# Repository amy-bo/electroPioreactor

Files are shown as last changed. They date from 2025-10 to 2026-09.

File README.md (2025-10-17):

# electroPioreactor

The electroPioreactor is a [Pioreactor](https://pioreactor.com) adapted to incorporate electrolysis and CO2 sparging.  The main motivation is to facilitate affordable, safe, local production of Hydrogen Oxidising Bacteria (HOB) as a sustainable alternative protein.

Our parametric [Vial Cap](Components/Vial%20Cap/) design and bill of materials are detailed in [Components](Components).

This repo also contains summary outputs of past research projects including [Harvey Mudd](Past%20research/HMC%20Final%20Outputs)'s anode and valve optimisation work and Brown's [CO2 sparger backflow solution](Past%20research/1.%20CO2%20backflow%20diagnosis%20-%20Eli%20Silver.md).



## Aseptic electroPioreactor

A current focus is development and testing of an Aseptic electroPioreactor to facilitate research on monocultures. [Imperial College](https://profiles.imperial.ac.uk/s.billerbeck/grants) and [Edinburgh University](https://biology.ed.ac.uk/chris-french-laboratory) are leading this work under [CARMA Hub Pump Priming](https://carmahub.co.uk/about-us/pump-priming-projects/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) funding.

## GitHub & Radicle

This repo is synchronised both [via GitHub](https://github.com/amy-bo/electroPioreactor/tree/main) and [via Radicle](https://app.radicle.xyz/nodes/iris.radicle.xyz/rad%3AzY4GuyErQo91xGYdLi4r2bea9QDJ) we would encourage you to try [Radicle.xyz](https://radicle.xyz/).

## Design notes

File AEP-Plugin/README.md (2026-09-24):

# electroPioreactor-plugin

A [Pioreactor](https://pioreactor.com) community plugin for the **[electroPioreactor](https://electroPioreactor.org)** – any Pioreactor fitted with an electrode pair driven by LED D and a CO₂ solenoid driven by PWM channel 4.

Provides a single background job, **electroPioreactor**, that:

- Drives electrolysis (via LED channel D) at a user-defined power level (0–10 %, clamped at runtime to protect the electrodes).
- Sparges CO₂ by periodically opening a CO₂ solenoid (PWM channel 4 relay) for a user-defined duration, at a user-defined interval in minutes.
- Automatically pauses electrolysis (LED D → 0 %) for the duration of each sparge and resumes it immediately after.
- Pauses the `od_reading` job for the duration of the sparge plus a user-defined settle window, so OD samples aren't contaminated by bubbles.

All four user-defined parameters are editable live from the Pioreactor web interface.

### OD pausing

`od_pause_after_sparge_seconds` (default `5.0`) is the number of seconds **after the CO₂ solenoid closes** before OD reading resumes – the bubble-clearance window. The total OD pause window is `sparge_duration_seconds + od_pause_after_sparge_seconds`, measured from sparge start.

- **Positive** → pause OD for the full sparge plus N seconds of settle time. Typical.
- **Zero** → resume OD the instant the solenoid closes.
- **Negative** → resume OD part-way through the sparge (OD continues through the tail end of sparging).
- **≤ −`sparge_duration_seconds`** → total pause ≤ 0; OD is not paused at all. Use a large negative (e.g. `-99999`) to disable the feature entirely.

Pause/resume is done by publishing `JobState.SLEEPING`/`READY` to `od_reading`'s `$state/set` topic. If `od_reading` isn't running, the publish is a no-op.

## Hardware requirements

- Pioreactor with an electrode pair wired to **LED channel D**.
- CO₂ solenoid valve wired to **PWM channel 4**.
- CO₂ supply (e.g. SodaStream) ideally with a needle valve for flow control.

## Installation

### From the card

Needs a Pioreactor OS release with boot-partition plugin support (proposed at https://github.com/amy-bo/CustoPiZer/tree/bootfs-plugins and accepted by Pioreactor; until it ships, use the SSH route below).

1. Two changes to make while following Pioreactor's software set-up guide, which comes next:
   - At its step 3, in **App Options**, switch off **Eject media when finished** (1) before you set the **Content Repository** (2), so the card stays mounted after the write.

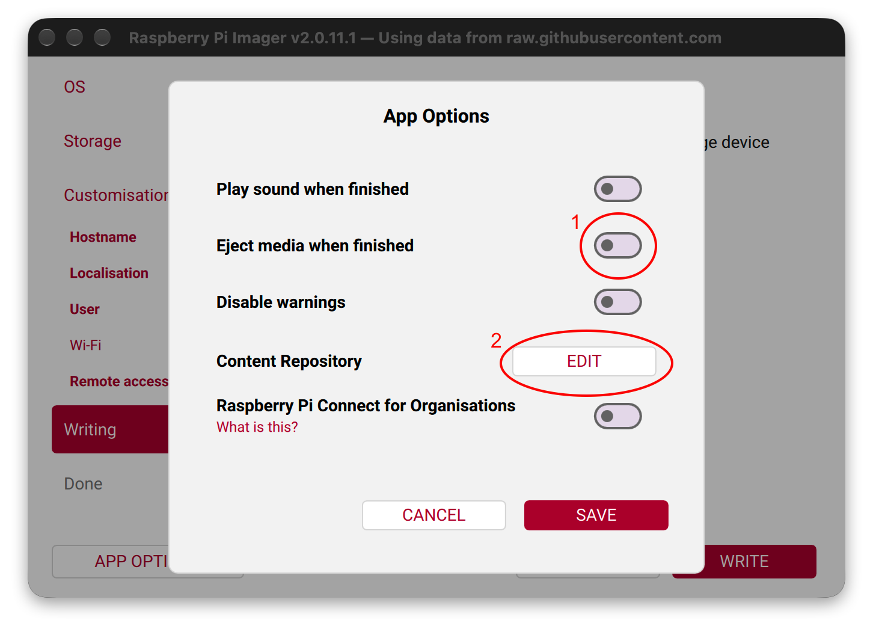
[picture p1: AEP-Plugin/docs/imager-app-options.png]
Imager's App Options: 1 Eject media when finished switched off, 2 Content Repository Edit
     

   - At its step 15, for your leader, leave the Wi-Fi page blank if you can't add devices to your lab's Wi-Fi then reach them through it (typical at universities); the leader Pioreactor then makes its own network.
   - Worker-only units: follow the same steps with a **Worker** image. Flash each worker with the step 15 Wi-Fi page set to network `pioreactor`, password `raspberry`, and at step 3 below do not drag the `local_access_point` file across. The plugin installs when you add the unit from the leader's **Inventory** page. Hotspot cluster: boot the leader first.

   With those in mind, follow [Pioreactor's software set-up guide](https://docs.pioreactor.com/user-guide/software-set-up) up to **Write**, and come back here while the card writes.
2. Download and unzip the [AEP card bundle](https://github.com/amy-bo/electroPioreactor/releases/latest/download/electroPioreactor-AEP-card-bundle.zip).
3. When the write finishes, drag the `pioreactor` folder from the bundle onto the `bootfs` drive. If you left the Wi-Fi page blank (for the leader Pioreactor to make its own network), also drag across the `local_access_point` file, after changing `GB` in it to your country code\*. DO NOT drag it across for workers, or if you set your Pioreactors up to join a Wi-Fi network. If the card was ejected anyway, remove and reinsert it.
4. Eject the card. One change to the rest of Pioreactor's guide: for a unit that makes its own Wi-Fi, join the network `pioreactor` (password `raspberry`) and open `http://pioreactor.local`. Then continue the guide from its step 18; the model dialog at its step 21 does not appear, because the bundle has set the model. **electroPioreactor** is under **Activities** on the unit's *Manage* page, and the precision temperature plugin is installed.

   \* If your country code is not GB, open `local_access_point` in TextEdit/Notepad and replace `GB` with the ISO two-letter code (CA, IE, DE, AU, NZ, GL, US, etc.; see https://en.wikipedia.org/wiki/ISO_3166-1_alpha-2) and save; the file should contain just those two letters. Do nothing if you live in the United Kingdom of Great Britain and Northern Ireland (GB).

MEP kit: the same steps with the [MEP card bundle](https://github.com/amy-bo/electroPioreactor/releases/latest/download/electroPioreactor-MEP-card-bundle.zip); there is no precision temperature plugin.

If it is missing, put the card back in your computer: `pioreactor/plugins/failed/` on `bootfs` holds the wheel and a log of what went wrong.

### Over SSH

For a unit that is already running, or an OS release without boot-partition plugin support.

1. Download and unzip the [AEP card bundle](https://github.com/amy-bo/electroPioreactor/releases/latest/download/electroPioreactor-AEP-card-bundle.zip) (or the [MEP card bundle](https://github.com/amy-bo/electroPioreactor/releases/latest/download/electroPioreactor-MEP-card-bundle.zip)) on your computer.
2. In a terminal, from the unzipped `pioreactor/plugins` folder, with `<hostname>` replaced by the unit's name. Each command asks for the unit's password; answer `yes` if asked about a fingerprint.

   ```bash
   scp *.whl pioreactor@<hostname>.local:
   ssh pioreactor@<hostname>.local 'for w in *.whl; do n=${w%%-*}; /opt/pioreactor/venv/bin/pio plugins install ${n//_/-} --source "$w"; done'
   ```

   The second command installs every wheel in the folder, naming each plugin from its file.

3. Refresh the unit's web interface: **electroPioreactor** is under **Activities** on the *Manage* page.

## Configuration

Installation sets these defaults:

```ini
[PWM]
4=relay

[electropioreactor.config]
electrolysis_power=2.5              ; LED D intensity (0–10 %, clamped at runtime)
sparge_duration_seconds=10.0        ; solenoid open time per cycle (s)
sparge_interval_minutes=60.0        ; cycle frequency (min)
od_pause_after_sparge_seconds=5.0   ; OD settle window after sparge ends (s); negative allowed
```

Change them on the Pioreactor **Configuration** page, or live in the job's **Settings** panel while it runs. A new `od_pause_after_sparge_seconds` applies from the next sparge.

## Starting the job

In the web interface: open **Activities** on the *Manage* page and start **electroPioreactor**. All four parameters can be changed live from **Settings** without restarting.

From the command line:

```bash
pio run electropioreactor \
    --electrolysis-power 2.5 \
    --sparge-duration-seconds 10 \
    --sparge-interval-minutes 60 \
    --od-pause-after-sparge-seconds 5
```

## Pioreactor version

Requires Pioreactor 26.5.0 or later. On an older unit, run `pio update` first.

## Development

```bash
git clone https://github.com/amy-bo/electroPioreactor.git
cd electroPioreactor/AEP-Plugin
pip install -e ".[dev]"
pytest tests/                   # off-device, no Pi needed
```

## Contributing

Issues and pull requests welcome at <https://github.com/amy-bo/electroPioreactor>.

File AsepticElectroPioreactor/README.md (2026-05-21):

# Aseptic electroPioreactor (AEP)

The **Aseptic electroPioreactor (AEP)** is a variant of the [electroPioreactor](../) developed for reproducible monoculture research on Hydrogen Oxidising Bacteria (HOB). It is based on the [Pioreactor](https://pioreactor.com), adapted to add in-culture electrolysis and CO₂ sparging; the "Aseptic" variant adds the gas-line filtration, sealing and autoclave-ability needed to keep a monoculture free of contamination.

In-culture electrolysis generates H₂ (at the cathode) and O₂ (at the anode) *in situ* from the medium, so HOB can fix CO₂ autotrophically without the hazards of sparged hydrogen.

## Why an AEP?

- **Safe** – hydrogen and oxygen are produced only as needed, dissolved in the medium, rather than stored.
- **Aseptic** – luer-lock 0.2 μm vent filters on entry/exhaust ports and a sealed vial cap allow defined monoculture work.
- **Affordable** – built on the low-cost open Pioreactor platform, supplied in the UK by [LabCrafter](https://labcrafter.co.uk) and in the rest of the world by [Pioreactor](https://pioreactor.com).
- **Automated** – turbidostat dosing, peristaltic media/product handling, and relay-driven intermittent CO₂ sparging all run from the Pioreactor UI using the [electroPioreactor plugin](../AEP-Plugin).
- **Open & reproducible** – parametric designs, BoM and assembly procedures are version-controlled here.

Design criteria, applied in order: 
1. Safe
2. Accurate & repeatable
3. Automated
4. Good value

## Origins

The electroPioreactor was created by [AMYBO](https://amybo.org) to facilitate affordable, safe, local production of HOB as a sustainable alternative protein.

The **Aseptic** variant focuses that platform on monoculture research. The current AEP0.1 line was assembled and trained on by Imperial and Edinburgh students in November 2025 (see [AEP0.1 Training](CARMA_PumpPriming/Results/AEP0.1%20Training/README.md)).

## CARMA Hub Pump Priming

This work is funded under [**CARMA Hub Pump Priming**](https://carmahub.co.uk/about-us/pump-priming-projects/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) ("Affordable Aseptic Electro-Bioreactor for Reproducible HOB Research"), led by:

- [Dr Sonja Billerbeck](https://profiles.imperial.ac.uk/s.billerbeck) – PI, Imperial College London (Bezos Centre for Alternative Proteins)
- [Prof. Chris French](https://biology.ed.ac.uk/chris-french-laboratory) – PI/collaborator, University of Edinburgh

with [AMYBO](https://amybo.org) as design and training subcontractor/collaborator and [LabCrafter](https://labcrafter.co.uk) as named vendor.

## Directory

- 🗂 [**CARMA_PumpPriming/**](CARMA_PumpPriming) — AEP work under CARMA Hub Pump Priming
  - [Meetings.md](CARMA_PumpPriming/Meetings.md) — meeting notes
  - 🗂 [**Assembly/**](CARMA_PumpPriming/Assembly) — build procedures
    - [README.md](CARMA_PumpPriming/Assembly/README.md) — **latest** assembly instructions (AEP0.1.1)
    - [AEP0.1.1_Assembly.md](CARMA_PumpPriming/Assembly/AEP0.1.1_Assembly.md) — pointer to latest instructions
    - 🗂 [**Superseded/**](CARMA_PumpPriming/Assembly/Superseded) — earlier assembly docs
      - [AEP0.1_Assembly.md](CARMA_PumpPriming/Assembly/Superseded/AEP0.1_Assembly.md)
      - [AEP0.1 Assembly.opml](CARMA_PumpPriming/Assembly/Superseded/AEP0.1%20Assembly.opml)
  - 🗂 [**Results/**](CARMA_PumpPriming/Results) — experimental results
    - 🗂 [**AEP0.1 Training/**](CARMA_PumpPriming/Results/AEP0.1%20Training) — Nov 2025 joint training (Imperial + Edinburgh)
      - [README.md](CARMA_PumpPriming/Results/AEP0.1%20Training/README.md) — training write-up
      - [Training Notes (Biological and experimental notes - Amir).docx](CARMA_PumpPriming/Results/AEP0.1%20Training/Training%20Notes%20%28Biological%20and%20experimental%20notes%20-%20Amir%29.docx)
      - [AnodeDiscolouration.jpg](CARMA_PumpPriming/Results/AEP0.1%20Training/AnodeDiscolouration.jpg)
    - 🗂 [**Anode discolouration/**](CARMA_PumpPriming/Results/Anode%20discolouration) — anode discolouration images
    - 🗂 [**Gas sparging/**](CARMA_PumpPriming/Results/Gas%20sparging) — CO₂ sparging investigation
      - [Continuous or Intermittent CO2 sparging.md](CARMA_PumpPriming/Results/Gas%20sparging/Continuous%20or%20Intermittent%20CO2%20sparging.md)
      - [EXAPURE_Filters_2009.pdf](CARMA_PumpPriming/Results/Gas%20sparging/EXAPURE_Filters_2009.pdf)
      - [Measuring cylinder recently full of CO2 IMG_8702.DNG](CARMA_PumpPriming/Results/Gas%20sparging/Measuring%20cylinder%20recently%20full%20of%20CO2%20IMG_8702.DNG)

---
<sub>O4.7: this README was drafted by Claude (Opus 4.7) from repo contents & reviewed by Martin Currie.</sub>

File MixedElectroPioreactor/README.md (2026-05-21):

# Mixed-culture electroPioreactor (MEP)

The MEP was the only electroPioreactor until we started work on the [Aseptic electroPioreactor (AEP)](../AsepticElectroPioreactor) for use with single strains. We are now resuming work on the MEP as a lower-cost version for mixed-culture use, initially producing two units for the 2026 MSc Industrial Projects of the [School of Biological Sciences](https://biology.ed.ac.uk/) at the University of Edinburgh.

For the wider electroPioreactor project see [electropioreactor.org](https://electropioreactor.org).

## Documents in this folder

- [Assembly](Assembly-EdMSc26.md)
- [Calibration](Calibration.md)
- [Operation](Operation.md)
- [Pre-Transport Check](PreTransportCheck-EdMSc26.md)

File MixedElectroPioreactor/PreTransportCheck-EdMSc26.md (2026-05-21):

# MEP Pre-Transport Check (ed04, ed05)

Bench checks Martin runs in Newmilns the week before transport to Edinburgh, so that on arrival the only remaining steps are: media fill, the bagged-anode install on ed04, and (for both units) a SodaStream attach.

Two MEP0.02 units in scope: **ed04** and **ed05** each set up as solo leader-workers. ed01–ed03 are Bingqiao's, already in active use in Chris French lab. ed04 will receive the new RPi Zero 2W once ed05 confirmed working then the bagged Pt-plated Ti anode at Edinburgh; ed05 has all the newest other parts and its electrodes are already installed and will not change.

The values Martin records below are the references students will compare their own measurements to during [Calibration.md](Calibration.md). Each "**Record:**" line is a deliberate action, not just a tick.

## Why incomplete?

Martin was first unable to locate both magnetic fleas.  Then he couldn’t find two vials large enough to sit tightly within the Pioreactor 1.1 vial o-ring (were the original v1.0 vials narrower?) so he decided to devise a means of tubing all overflow into a central centrifuge tube then into a central GL45 flask.  Then each unit dramatically failed self-tests, this was eventually diagnosed to be an issue with the electroPioreactor plugin changing case of the config file.  One of the TopStop screws was overtightened, causing the PCCF TopStop to break.  By the time these issues were resolved and the following checked items were done, it was 7am.

## Bench tests

Run on ed05, then swap pio01's RPi 4B for the new RPi Zero 2W, insert ed04's TF, and repeat on ed04. Each check below has paired ed05 and ed04 boxes so you can tick per unit. Don't transport a unit with an unticked row.

### 1. Boot and network

- [x] ed05: Power on, Pi boots within ~90 s - 35s
- [x] ed04: Power on, Pi boots within ~90 s
- [x] ed05: Web UI reachable at http://ed05.local/
- [x] ed04: Web UI reachable at http://ed04.local/
- [x] ed05: Activity dashboard updates live (local MQTT broker up)
- [x] ed04: Activity dashboard updates live (local MQTT broker up)
- [x] ed05: `amybo` + own-hotspot fallback configured via nmcli (autoconnect-priority 20 / 0)
- [x] ed04: `amybo` + own-hotspot fallback configured via nmcli (autoconnect-priority 20 / 0)
- [x] ed05: `amybo` off → falls back to own hotspot within ~60 s, SSH via 10.42.0.1 works
- [x] ed04: `amybo` off → falls back to own hotspot within ~60 s, SSH via 10.42.0.1 works
- [x] ed05: `amybo` back on → rejoins, SSH via ed05.local works
- [x] ed04: `amybo` back on → rejoins, SSH via ed04.local works

### 2. Stirring

- [x] ed05: Stirring starts from web UI, fan spins, no rattle
- [x] ed04: Stirring starts from web UI, fan spins, no rattle
- [x] ed05: Stops cleanly
- [x] ed04: Stops cleanly

### 3. Solenoid (CO₂ relay on PWM 4)

- [x] ed05: With CO₂ cylinder open and needle valve cracked, manual relay-on produces a visible bubble stream into the vial via the entry filter
- [x] ed04: With CO₂ cylinder open and needle valve cracked, manual relay-on produces a visible bubble stream into the vial via the entry filter
- [x] ed05: Solenoid clicks audibly on each toggle
- [x] ed04: Solenoid clicks audibly on each toggle
- [x] ed05: Closes cleanly with no continued bubbling
- [x] ed04: Closes cleanly with no continued bubbling

### 4. Wet electrolysis

ed05 bench-tests with its own installed electrodes (the experiment set, not changing). Those electrodes are then moved to ed04 for its bench test and returned to ed05 afterwards. ed04 is left with the bagged fresh Pt-plated Ti anode at Edinburgh, where a new reference V and I are recorded.

- [x] ed05: Vial filled with bicarbonate solution, electrodes at standard depth
- [x] ed04: Vial filled with bicarbonate solution, electrodes at standard depth
- [x] ed05: LED D set to **2.5 %**
- [x] ed04: LED D set to **2.5 %**
- [x] ed05: Bubbles visible on both electrodes within 30 s; cathode bubble rate roughly twice anode rate
- [x] ed04: Bubbles visible on both electrodes within 30 s; cathode bubble rate roughly twice anode rate
- [ ] **Record (ed05 only):** V across electrodes ____ V, I through electrodes ____ mA. This is the reference for [Calibration § 6](Calibration.md#6-electrolysis-v-and-i-at-25--led-d).
- [ ] **Record (ed04, sanity only):** V ____ V, I ____ mA. Student reference for ed04 is set on arrival post-anode-swap.
- [x] ed05: LED D back to 0 % at end of test
- [x] ed04: LED D back to 0 % at end of test

### 5. Pumps

- [x] ed05: Media pump (PWM 3) ticks forwards on a manual dose, fluid moves through
- [x] ed04: Media pump (PWM 3) ticks forwards on a manual dose, fluid moves through
- [x] ed05: Waste pump (PWM 2) ticks forwards on a manual dose, fluid moves through
- [x] ed04: Waste pump (PWM 2) ticks forwards on a manual dose, fluid moves through
- [x] ed05: Both stop cleanly
- [x] ed04: Both stop cleanly

## Solenoid leak check

All three threaded ports around the HPcontrols solenoid (regulator side, needle-valve side, blanking-plug side) were sealed with **Loctite 577 anaerobic thread sealant** for the first time on 2026-04-30. Cure is well past. Two checks below.

### A. Baseline flow comparison vs AEP0.1.1's ODL setup

The AEP0.1.1 reference uses the [Premium ODL SodaStream regulator](../Components/CO2%20transfer/Regulators.md) at 1 bar. FZone has a fixed, non-adjustable outlet pressure, so MEP flow is set by the needle valve alone. We want MEP flow comparable to ODL@1bar so the experiment regime ports across.

- [ ] Connect ed04's FZone + solenoid + needle-valve stack to its SodaStream
- [ ] With solenoid held open and needle valve cracked, time to fill a 100 ml inverted measuring cylinder over water: ed04 ____ s, ed05 ____ s
- [ ] Repeat with AEP0.1.1's ODL stack (regulator at 1 bar): reference ____ s
- [ ] **Record:** needle-valve setting (turns from fully closed) that makes each MEP fill comparably to the ODL reference: ed04 ____ turns, ed05 ____ turns. Target for [Calibration § 5](Calibration.md#5-co-flow-rate).
- [ ] **Record:** ml CO₂ per second of solenoid-open at the target setting: ed04 ____ ml/s, ed05 ____ ml/s. Target for [Calibration § 5](Calibration.md#5-co-flow-rate).

### B. Pressure-decay (snoop + rate-stability)

FZone has cylinder and outlet gauges, so a glance at the outlet gauge during a quiescent period is the first tell. The two checks below are the more sensitive follow-ups for the slow leaks Loctite-577 might still let through: snoop with soapy water, then watch flow-rate stability over 30 min.

- [ ] Cylinder open, needle valve closed downstream of solenoid, solenoid open
- [ ] Outlet gauge holds steady for 60 s with the needle valve closed: ed05 ____ , ed04 ____ (any drop = leak upstream of the needle valve)
- [ ] Paint soapy water onto each Loctite-577 joint; observe per joint for 60 s, no new bubbles = pass
- [ ] Open needle valve to a steady bubble rate into a water bath; record initial bubbles per minute, leave 30 min, recount
- [ ] Cylinder closed at end of test, system bled down before pack

## Pack and transport

- [x] Vial drained, rinsed, dried, packed inside Pioreactor
- [x] Solenoid + needle valve + regulator stack kept assembled; SodaStream **detached** for transport
- [x] ed04's spare bagged anode kept sealed in its bag
- [x] PSUs, multimeter, balance, bicarbonate solution in the kit box
- [x] microSD reader (already owned in laptop case for on-site recovery if `amybo` fallback misbehaves)

## On arrival (Edinburgh, Martin)

- [x] Tighten each unit's SodaStream onto its FZone regulator (cryo gloves on for the swift tighten).
- [ ] **ed04 only:** unbag the fresh Pt-plated Ti anode, install through the captive-nut [Electrode Top Stop](../Components/ElectrodeTopStop) following [Assembly § Electrodes](Assembly-EdMSc26.md#electrodes-ed04-only--fresh-anode), set down to standard depth.
- [ ]  **ed04 only:** re-run [wet electrolysis](#4-wet-electrolysis) at 2.5 % LED D. **Record:** new V ____ V, new I ____ mA. This is the student reference for ed04 (the bench numbers above were for the now-removed test electrodes).
- [ ]  Fill media bottles, prime media and waste pumps.
- [ ]  If a unit needs the relay or electroPioreactor plugin reinstalled, click **Plugins** in the left nav rather than dropping to a shell (the CLI fallback is `pio plugins install <name-of-plugin> --source <location of .whl file>`).
- [x]  Hand off to students for [Assembly](Assembly-EdMSc26.md) → [Operation](Operation.md) → [Calibration](Calibration.md).

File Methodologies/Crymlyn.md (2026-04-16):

# Home HOB Enrichment Methodology – Crymlyn Fen

A home-lab protocol for enriching hydrogen-oxidising bacteria (HOB) from environmental samples using the [AEP0.1](https://github.com/amy-bo/electroPioreactor) electroPioreactor. Developed for the AMYBO community; intended as a living document to be iterated on as results come in.

---

## Medium

Two formulation options are presented. Option A is [MC02](https://github.com/amy-bo/electroPioreactor/tree/main/Media), the medium used in the CARMA Hub project by Imperial College and University of Edinburgh, adapted only where necessary for home accessibility. Option B is a potential literature synthesis that is more accessible to home users who cannot source NaH₂PO₄·2H₂O, but departs more from [MC02](https://github.com/amy-bo/electroPioreactor/tree/main/Media) and results will not be directly comparable with CARMA Hub experiments. For results directly comparable with CARMA Hub experiments, use Option A.

---

### Option A – [MC02](https://github.com/amy-bo/electroPioreactor/tree/main/Media) (recommended for CARMA Hub compatibility)

#### Mesonutrients (per litre final medium)

| Component | Formula | Amount |
|---|---|---|
| Disodium hydrogen phosphate | Na₂HPO₄ | 2.895 g |
| Sodium dihydrogen phosphate dihydrate | NaH₂PO₄·2H₂O | 3.060 g |
| Potassium sulphate | K₂SO₄ | 0.170 g |
| Calcium sulphate dihydrate | CaSO₄·2H₂O | 0.097 g |
| Magnesium sulphate heptahydrate | MgSO₄·7H₂O | 0.800 g |
| Ammonium sulphate | (NH₄)₂SO₄ | 0.943 g |

This gives a phosphate buffer molarity of ~40 mM and a conductivity of ~6.1 mS/cm, consistent with Sydow et al. (2017) optimal medium. MgSO₄ at 0.800 g/L follows Sydow et al. (2017) and [MC02](https://github.com/amy-bo/electroPioreactor/tree/main/Media); Givirovskiy et al. (2019) use 0.5 g/L. Either is defensible; 0.800 g/L is used here for [MC02](https://github.com/amy-bo/electroPioreactor/tree/main/Media) consistency.

> **CaSO₄ preparation note:** CaSO₄·2H₂O (gypsum) has very low solubility (~2.4 g/L at 25°C). At 0.097 g/L the working concentration is well within this limit, but a concentrated stock is not feasible. Add CaSO₄·2H₂O directly to the final medium volume rather than preparing a stock solution. Home source: homebrew/winemaking supplier (food-grade gypsum).

> **NaH₂PO₄·2H₂O availability note:** Monosodium phosphate dihydrate is available from online laboratory suppliers (e.g. Labpals, Sigma via Amazon). If genuinely unavailable, see Option B for a KH₂PO₄-based alternative and its trade-offs.

#### Trace elements – Iron Solution (make 100 mL, dose 3.40 mL per litre of medium)

| Component | Formula | Amount |
|---|---|---|
| Iron(II) sulphate heptahydrate | FeSO₄·7H₂O | 1.50 g |
| Hydrochloric acid (0.1 M) | HCl | to 100 mL |

H₂SO₄ at 0.2 M was chosen as the for MC02 as it has no chloride, no carbon source, lower vapour pressure than HCl, and longer shelf life. But H₂SO₄ is much less accessible domestically and more hazardous than the HCl used by Sydow et al. It should be avoided for home use.

HCl (sold as brick acid/patio cleaner at B&Q, typically 30–36%) may be more appropriate. It introduces a small chloride contribution, but at this dilution (~1.4 mg/L final concentration) it is negligible. HCl is Sydow et al.'s original acidulant, used by the Holtmann lab to this day. 

> **Alternative for avoiding liquid acids:** If you prefer not to handle or store HCl at home, Sodium Bisulphate (NaHSO₄, sold as dry granular pool "pH Reducer") may be an acceptable carbon-free, chloride-free alternative.  It introduces only Na⁺ and SO₄²⁻ which are already present in the medium. Dissolving 1.20 g of NaHSO₄ in 100 mL of distilled water yields a ~0.1 M acidic solution suitable for the iron stock.

> **Why not citric acid:** Citric acid is a readily metabolisable carbon source for heterotrophs and some HOB. In a protocol designed to select against heterotrophs in Stages 2–3, adding any free carbon source to the iron stock undermines the selective pressure and means autotrophic growth cannot be confirmed as the sole basis for OD increase. Note that ferric ammonium citrate, used by Givirovskiy et al. (2019) at 5 mg/L, is a different case – at that concentration the carbon load is negligible and chelation improves iron bioavailability. However, it introduces ammonium and is harder to source at home than FeSO₄, so it is not recommended here.

> **Iron stock shelf life:** Store in an amber bottle at 4°C. Purge headspace with CO₂ from the SodaStream after each use. Remake when the solution turns yellow-brown or precipitate appears.

#### Trace elements – Mineral Solution (make 1 L, dose 0.050 mL per litre of medium)
| Component | Formula | Concentration (g/L in 0.1 M HCl) |
|---|---|---|
| Sodium molybdate dihydrate | Na₂MoO₄·2H₂O | 1.8 |
| Zinc sulfate heptahydrate | ZnSO₄·7H₂O | 2.4 |
| Manganese(II) sulfate monohydrate | MnSO₄·H₂O | 2.4 |
| Copper(II) sulfate pentahydrate | CuSO₄·5H₂O | 0.48 |
| Nickel(II) sulfate hexahydrate | NiSO₄·6H₂O | 1.5 |
| Cobalt(II) sulfate heptahydrate | CoSO₄·7H₂O | 0.04* |

*If cobalt can't be obtained locally, or you would rather not work with a Category 1B carcinogen and SVHC (substance of very high concern) under REACH, you might attempt to skip it, hoping your HOB will obtain enough through “contamination as a feature”.

Store in amber bottle at 4°C.

#### Yeast extract (Stage 4 only)

1.0 g/L, prepared as a separate stock in distilled water and pressure-cooked before use. Do not include in Stages 2–3.

#### NaHCO₃ (optional)

0.10 g/L, added directly to the medium. In a CO₂-sparged reactor, dissolved inorganic carbon is replenished continuously by sparging and NaHCO₃ is not needed during normal operation. Include it if the reactor will be run without sparging for any period, as it provides an inorganic carbon reserve at startup.

#### Conductivity supplement (optional, for future optimisation)

Givirovskiy et al. (2019) add 5.45 g/L Na₂SO₄ to increase medium conductivity and reduce ohmic losses during electrolysis. This may materially help reduce ohmic constraints depending on current density and electrode geometry, and could be worth investigating once baseline enrichment is established. Na₂SO₄ is available as washing soda decahydrate from hardware shops. Not recommended for first enrichment attempts; record baseline conductivity and voltage first.

---

### Option B – Potential literature synthesis

This option is more accessible to home users who cannot source NaH₂PO₄·2H₂O, but departs more from [MC02](https://github.com/amy-bo/electroPioreactor/tree/main/Media) and results will not be directly comparable with CARMA Hub experiments.

#### Key differences from Option A

| Parameter | Option A ([MC02](https://github.com/amy-bo/electroPioreactor/tree/main/Media)) | Option B | Trade-off |
|---|---|---|---|
| Phosphate buffer | Na-based (NaH₂PO₄·2H₂O + Na₂HPO₄) | K/Na mixed (KH₂PO₄ + Na₂HPO₄) | Option B raises K⁺ from ~2 mM to ~20 mM. Dinges et al. (2024) show that neither all-K⁺ nor all-Na⁺ buffer performs as well as a mixed buffer for *C. necator*; 20 mM K⁺ is a meaningful departure from Sydow's optimum, though a second-order concern for an enrichment culture of unknown composition |
| Potassium source | K₂SO₄ (0.17 g/L, separate) | Via KH₂PO₄ (excess) | Option A gives tighter control of K⁺ |
| Nitrogen source | (NH₄)₂SO₄ | (NH₄)₂SO₄ | Same |
| Calcium source | CaSO₄·2H₂O | CaSO₄·2H₂O | Same |
| Iron acidulant | HCl | HCl (brick acid) | HCl more accessible at home |
| Trace elements | Full 6-component mineral solution | Full 6-component mineral solution | Same – see note below |

> **Trace element note:** Both options use the full 6-component mineral solution. Mn and Zn in particular are cofactors for key metalloenzymes in HOB and must not be omitted in Stages 2–3 where there is no yeast extract to compensate.

#### Option B mesonutrients (per litre)

| Component | Formula | Amount |
|---|---|---|
| Potassium dihydrogen phosphate | KH₂PO₄ | 2.67 g |
| Disodium hydrogen phosphate | Na₂HPO₄ | 2.90 g |
| Ammonium sulphate | (NH₄)₂SO₄ | 0.94 g |
| Magnesium sulphate heptahydrate | MgSO₄·7H₂O | 0.80 g |
| Calcium sulphate dihydrate | CaSO₄·2H₂O | 0.097 g |

CaSO₄ preparation note applies identically – add directly to final medium volume, do not prepare as a concentrated stock.

Iron solution and mineral solution: prepare as per Option A.

---

## Methodology

### Equipment and materials checklist

- AEP0.1 (fully assembled with electrodes, CO₂ sparging, and peristaltic pumps)
- SodaStream cylinder, connected and regulated
- Multimeter
- Stovetop pressure cooker
- Clean sealable sample jars (scalded with boiling water)
- OpenFlexure microscope
- Disposable sterile syringe (from pharmacy) for yeast extract addition in Stage 4
- Medium prepared as per chosen option above, without yeast extract
- Yeast extract stock prepared separately in distilled water and pressure-cooked
- 12V battery and leads (optional – see field pre-conditioning below)

---

### Safety note – hydrogen

Water electrolysis produces H₂ at the cathode. H₂ is explosive at 4–75% v/v in air. Before biomass is established and actively consuming H₂, headspace concentrations may approach or exceed the lower explosive limit. During all stages, and especially Stages 2–3 before growth is confirmed:

- Work in a well-ventilated space
- Keep all ignition sources away from the reactor (naked flames, sparking switches, unsleeved electrical connections)
- Do not seal the reactor headspace – the AEP0.1 vial must remain vented as designed

Once sustained growth is confirmed by rising OD, biomass consumption will keep headspace H₂ well below the explosive limit under normal operating conditions.

---

### Stage 1 – Sampling at Crymlyn Fen

> **NNR/SSSI note:** Crymlyn is a designated National Nature Reserve. Check with Natural Resources Wales whether a sampling licence is required before visiting with collection equipment. Do not skip this step.

Sample from an open water or swamp margin, not dense reed bed. The target community is at the oxic-anoxic interface where H₂ produced by anaerobes below diffuses upward into oxygenated water – this is where HOB naturally concentrate. Take a few centimetres of interface sediment and ~200 mL of overlying water from the same location. Avoid deep sediment, which will be dominated by methanogens and sulphate reducers.

Keep samples cool and dark during transport and process within 4 hours.

Take an OpenFlexure micrograph of the raw inoculum before doing anything else. This documents starting community morphology for comparison at later stages. 100× oil immersion will resolve rod vs coccus morphology and track gross community shifts but is not sufficient to identify HOB specifically.

> **Optional field pre-conditioning:** If travelling by car with a 12V battery available, the AEP0.1 can be run at the sampling site with fen water as the initial electrolyte, with a CO₂ sparge before departure and again on return. Pre-conditioning the community to electrolysis conditions before lab enrichment improves reproducibility of subsequent community development (Pagaling et al., 2014). The practical risks – electrolyte spillage, vibration disrupting electrode contacts, and difficulty maintaining temperature during transit – should be weighed against the benefits. If conditions are calm and the reactor can be secured safely, it may be worth doing; otherwise process the sample at home promptly.

---

### Stage 2 – Initial HOB selection (no yeast extract, no sterilisation required)

Without yeast extract, sterilisation of the medium is unnecessary. Environmental heterotrophs have no added carbon or energy source to bloom on in minimal mineral medium. H₂ and CO₂ selectively favour HOB from the outset.

Set the AEP0.1 to **30°C**. This is the standard temperature used across published HOB enrichments (Givirovskiy et al., 2019; Yang et al., 2021; Pous et al., 2022) and will substantially reduce lag phase compared with UK ambient temperatures of 17–21°C.

Fill the AEP0.1 to working volume (~14–15 mL with electrodes present). Before inoculating, run the reactor for 30 minutes with medium only and record the OD baseline. The electrodes are positioned above the OD light path and bubbles are not expected to sink into it, but establishing a pre-inoculation baseline is necessary to distinguish any residual scatter from genuine turbidity increases later.

Inoculate with ~0.7 mL (~5% v/v) of fen water with a small amount of interface sediment suspended within it.

**Begin electrolysis immediately.** In the AEP0.1, electrolysis is driven by LED D – the fourth LED channel on the Pioreactor HAT, repurposed to drive electrolysis current rather than its default illumination function. Set LED D power to 2.5%, or the lowest level that produces consistent visible bubble formation on both electrodes – whichever is higher. Record the resulting voltage and current using the multimeter. LED D power percentage is not transferable between different electrode configurations; voltage and current are the transferable reference values for anyone replicating this protocol with different hardware.

**Begin CO₂ sparging immediately.** CO₂ sparging serves two simultaneous purposes: supplying inorganic carbon for autotrophic growth, and purging excess O₂ from the headspace. Water electrolysis produces H₂ and O₂ at a 2:1 ratio but HOB consume them at approximately 4:1, so O₂ will accumulate in excess without active management. However, over-sparging will strip dissolved H₂ and CO₂ from the medium, directly limiting HOB growth. Use Pous et al. (2022) as the reference point: **twice-weekly 10-minute CO₂ flushes**. At higher electrolysis currents, O₂ may accumulate faster than this regime can clear in the AEP0.1's small working volume; if OD stalls or declines unexpectedly, increase to daily sparging as the first diagnostic step.

Set stir rate to **500 rpm** initially. Note the rate used – if results are unexpected, stir rate is a variable to revisit.

> **Troubleshooting:** If no OD increase above baseline is observed after several days, check electrode function with the multimeter to confirm current is flowing, confirm CO₂ sparging is operating, and consider collecting a fresh inoculum from a different location at the sampling site. The oxic-anoxic interface varies spatially; a different sampling point may yield a richer HOB community.

**Milestone to advance:** OD rising consistently and sustainably above the pre-inoculation baseline across multiple readings.

---

### Stage 3 – Pre-conditioning serial transfer

Once the Stage 2 milestone is met, transfer ~0.7 mL (~5% v/v) of the culture into a fresh vial of identical medium (no yeast extract, no sterilisation). Resume electrolysis, sparging, and temperature immediately. Take an OpenFlexure micrograph.

Repeat once more.

**Milestone to advance:** OD rising to a consistent level detectably faster in the second transfer than in the first.

---

### Stage 4 – Yeast extract boost

The HOB community established in Stages 2–3 now receives a growth boost via yeast extract, providing vitamins and trace organics that accelerate growth. This must be delivered in **batch mode**, not via the turbidostat. Even after two rounds of autotrophic selection, residual heterotrophs remain in the culture at low abundance. If yeast extract is introduced while the turbidostat is running, any heterotrophic growth it stimulates will be continuously amplified by dilution; delivering it as a batch pulse allows the culture to consume it and reach stationary phase before continuous dilution resumes, limiting the window during which heterotrophs can compete.

**Procedure:**

1. Turn off the turbidostat automation (switch to batch mode)
2. Using a disposable sterile syringe, add a pulse of pressure-cooked yeast extract stock directly to the running culture (target 1.0 g/L final concentration in the vial)
3. Allow the culture to consume it and reach stationary phase – indicated by OD plateauing and remaining stable for at least one hour
4. Switch the medium reservoir to yeast-extract-free medium and turn the turbidostat back on

The turbidostat will now gradually wash out any heterotrophs that grew on the yeast extract, while HOB continue on H₂ and CO₂.

**Milestone to advance:** OD stable through at least three volume turnovers of yeast-extract-free medium.

---

### Stage 5 – Electrolysis-dependence confirmation

Stop electrolysis. Continue CO₂ sparging and turbidostat operation unchanged. Confirm electrolysis has stopped by measuring current draw with the multimeter – it should drop to near zero.

If OD declines over subsequent readings and does not recover until electrolysis is restored, the culture is electrolysis-dependent. Restore electrolysis and confirm OD recovers.

Take a final OpenFlexure micrograph and compare morphology to the Stage 1 inoculum image.

**What this confirms:** The dominant organisms require electrolytically produced H₂ to grow. Obligate heterotrophs are absent or non-dominant.

**What this cannot confirm without sequencing:** Obligate chemolithotrophs and mixotrophs are not distinguishable by this protocol. Some facultative HOB (e.g. *Hydrogenophaga*, *Achromobacter*) can persist on trace organics even after washout. Electrolysis-dependence is a functional criterion, not a purity criterion – but for home-lab purposes it is the meaningful feasible endpoint.

---

## References

- Dinges et al. (2024) https://doi.org/10.1002/cssc.202301721
- Givirovskiy et al. (2019) https://doi.org/10.3390/en12101904
- Pagaling et al. (2014) https://doi.org/10.1038/ismej.2013.150
- Pous et al. (2022) http://doi.org/10.1016/j.biteb.2022.101010
- Pous et al. (2023) http://doi.org/10.1016/j.jece.2023.111550
- Sydow et al. (2017) https://doi.org/10.1002/elsc.201600252
- Yang et al. (2021) https://doi.org/10.1016/j.jclepro.2021.125921

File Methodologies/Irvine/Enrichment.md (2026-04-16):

# Irvine River HOB Enrichment – Enrichment Protocol

Lab enrichment stages for hydrogen-oxidising bacteria (HOB) following inoculum collection (see [Sampling.md](Sampling.md)) and medium preparation (see [Medium.md](Medium.md)).

---

## Safety note – hydrogen

Water electrolysis produces H₂ at the cathode. H₂ is explosive at 4–75% v/v in air. Before biomass is established and actively consuming H₂, headspace concentrations may approach or exceed the lower explosive limit. During all stages, and especially Stages 2–3 before growth is confirmed:

- Work in a well-ventilated space
- Keep all ignition sources away from the reactor (naked flames, sparking switches, unsleeved electrical connections)
- Do not seal the reactor headspace – the AEP0.1 vial must remain vented as designed

CO₂ is an asphyxiant at high concentrations. The volumes used here are small, but always sparge in a ventilated room, not a sealed enclosure.

Once sustained growth is confirmed by rising OD, biomass consumption should keep headspace H₂ below the explosive limit under normal operating conditions.

---

## Equipment and materials checklist

Before starting, confirm the following are available and functional:

- AEP0.1 (fully assembled with electrodes, CO₂ sparging, and peristaltic pumps)
- SodaStream cylinder, connected and regulated
- Measuring cylinder (>15 ml)
- Basin large enough to collect gas in measuring cylinder over water
- Multimeter
- Pressure cooker
- Clean centrifuge tubes (scalded with boiling water)
- Disposable sterile syringe for yeast extract addition in Stage 4
- Medium prepared as per [Medium.md](Medium.md), without yeast extract
- Yeast extract stock prepared separately in distilled water and pressure-cooked

---

## Stage 1 – Pre-run calibrations

Complete all calibrations before collecting field samples. The inoculum should go into a running, calibrated reactor with as little delay as possible.

### 1a. Pioreactor calibrations

Follow the standard Pioreactor calibration procedures for OD sensor and peristaltic pumps. Record all calibration values.

### 1b. CO₂ sparge volume calibration

The AEP0.1 headspace is approximately 3 mL (20 mL vial minus 15 mL liquid minus ~2 mL of submerged electrodes and tubing). Each sparge event delivers 15 mL of CO₂. The sparging tube terminates at the anode base, so CO₂ bubbles rise through the upper portion of the liquid column before displacing the headspace. This both saturates the liquid with dissolved CO₂ as the carbon source for autotrophic growth, and strips dissolved O₂ away from the cathode to prevent parasitic cathodic O₂ reduction (see Stage 2 sparging rationale).

**Calibration procedure:**

1. Fill an inverted measuring cylinder with water and submerge the open end in a basin of water
2. Direct the CO₂ sparging tube into the measuring cylinder
3. Open the solenoid valve for a timed interval (start with 5 seconds) and record the volume of water displaced
4. Repeat at 3, 5, 10 and 15 seconds to establish a flow-rate curve
5. Determine the solenoid-open duration that delivers 15 mL; this is **one sparge event**

Record the calibrated sparge duration. This value is hardware-specific and must be re-measured if the SodaStream cylinder, solenoid, or tubing is changed.

---

## Stage 2 – Initial HOB selection (no yeast extract, no sterilisation required)

Without yeast extract, sterilisation of the medium is unnecessary. Environmental heterotrophs have no added carbon or energy source to bloom on in minimal mineral medium. H₂ and CO₂ selectively favour HOB from the outset.

Set the AEP0.1 to **30°C**. This is the standard temperature used across published HOB enrichments (Givirovskiy et al., 2019; Yang et al., 2021; Pous et al., 2022) and will substantially reduce lag phase compared with UK ambient temperatures.

Add 15 mL of medium. Before inoculating, run the reactor for 30 minutes with medium only and record the OD baseline. The electrodes are positioned above the OD light path and bubbles are not expected to sink into it, but establishing a pre-inoculation baseline is necessary to distinguish any residual scatter from genuine turbidity increases later.

Set stir rate to **500 rpm** initially. Note the rate used – if results are unexpected, stir rate is a variable to revisit.

**Begin electrolysis.** In the AEP0.1, electrolysis is driven by LED D – the fourth LED channel on the Pioreactor HAT, repurposed to drive electrolysis current rather than its default illumination function. Set LED D power to 2.5%, or the lowest level that produces consistent visible bubble formation on both electrodes – whichever is higher. Record the resulting voltage and current using the multimeter. LED D power percentage is not transferable between different electrode configurations; voltage and current are the transferable reference values for anyone replicating this protocol with different hardware.

**Begin automated CO₂ sparging.** Sparging serves two purposes: supplying dissolved CO₂ as the carbon source for autotrophic growth, and stripping dissolved O₂ to protect cathodic H₂ evolution. Water electrolysis produces H₂ and O₂ at a 2:1 molar ratio; HOB consume them at approximately 4:1, so excess O₂ accumulates. If dissolved O₂ reaches the cathode, it is preferentially reduced back to water (O₂ + 4H⁺ + 4e⁻ → 2H₂O is thermodynamically favoured over 2H⁺ + 2e⁻ → H₂), consuming current without producing H₂. This "oxygen recycling" was identified as a major efficiency loss by Pous et al. (2022). The purge target is therefore low cathode-local dissolved O₂ - not low ambient O₂ for the bacteria themselves, which are aerobic.

**Frequency: 8× per day (every 3 hours)**, using the calibrated sparge duration from Stage 1b. This is an initial estimate; optimal frequency for preventing cathodic O₂ reduction at the operating current has not been determined empirically. Monitor current draw during operation - if current rises without corresponding bubble formation at the cathode (indicating O₂ reduction rather than H₂ evolution), increase sparge frequency.
Pause electrolysis during each sparge event (LED D → 0% for the sparge duration) to avoid simultaneous anodic O₂ generation working against the purge. Restore LED D to its operating power immediately after the sparge completes.

**Inoculate via sediment elutriation.** In a clean tube, combine ~1 mL of collected sediment with ~5 mL of river water from the same sampling site. Cap and shake vigorously for 30 seconds. Let coarse material settle for 1-2 minutes. Draw 750 μL (5% v/v) from the upper portion of the liquid for inoculation, avoiding the settled grit at the bottom. This concentrates sediment-associated microbes (including HOB, which are more abundant in sediment than in overlying water) while excluding the coarse mineral fraction that would otherwise risk scratching electrodes, jamming the stir bar, or contributing to OD noise.

**Operating mode: batch with manual volume maintenance.** Stage 2 runs in batch mode - no turbidostat or chemostat automation. At low initial cell densities, any dilution would wash out the sparse inoculum before it could establish. However, evaporative loss through the vent stubs at 30°C is significant over 10-14 days and will concentrate salts, drop the liquid level below the OD path, and eventually expose electrodes. Pause OD measurement and check the liquid level daily, manually pumping in sterile deionised water (not fresh medium) to maintain 15 mL. Topping up with medium would progressively concentrate salts; topping up with water replaces only what has evaporated.

**OD growth expectations.** Do not expect detectable OD increases for at least 10–14 days. Environmental HOB are present at low abundance in river water; the inoculum starts at perhaps 10³–10⁴ relevant cells/mL. Autotrophic HOB doubling times are 6–24 hours under favourable conditions and likely longer during initial adaptation. Many doublings are needed before the culture reaches the Pioreactor's OD detection threshold. This lag is normal and consistent with published enrichment timescales.

> **Troubleshooting:** If no OD increase above baseline is observed after 14 days, check electrode function with the multimeter to confirm current is flowing, confirm CO₂ sparging is operating, and consider collecting a fresh inoculum from a different location along the river. The oxic–anoxic interface varies spatially; a different sampling point may yield a richer HOB community.

**Milestone to advance:** OD rising consistently and sustainably above the pre-inoculation baseline. Initial increases may be marginal and only distinguishable from noise by trend across 24–48 hours of readings.

---

## Stage 3 – Pre-conditioning serial transfer

Once the Stage 2 milestone is met, transfer 750 μL (5% v/v) of the culture into a fresh vial of identical medium (no yeast extract, no sterilisation). Resume electrolysis, sparging, and temperature immediately.  Stage 3 also runs in batch mode; maintain daily volume top-ups with sterile deionised water as in Stage 2.

Repeat once more.

**Milestone to advance:** OD rising to a consistent plateau in the second transfer at a similar or higher level to the first, demonstrating the culture is self-sustaining across transfers. With a single enrichment line, genuine community refinement cannot be distinguished from stochastic variation between transfers; the meaningful test is self-sustainability, not speed of growth.

---

## Stage 4 – Yeast extract boost

The HOB community established in Stages 2–3 now receives a growth boost via yeast extract, providing vitamins and trace organics that accelerate growth. The yeast extract is delivered as a batch pulse before the turbidostat is started. Even after two rounds of autotrophic selection, residual heterotrophs remain in the culture at low abundance. Delivering yeast extract as a batch pulse allows the culture to consume it and reach stationary phase before continuous dilution begins, limiting the window during which heterotrophs can compete. Once the pulse has been consumed and the medium reservoir switched to yeast-extract-free medium, the turbidostat is started for the first time; it then gradually washes out any heterotrophs that grew on the yeast extract while HOB continue on H₂ and CO₂.

**Procedure:**

1. Using a disposable sterile syringe, add a pulse of pressure-cooked yeast extract stock directly to the running culture (target 1.0 g/L final concentration in the vial)
2. Allow the culture to consume it and reach stationary phase – indicated by OD plateauing and remaining stable for at least 6 hours
3. Switch the medium reservoir to yeast-extract-free medium and start the turbidostat

**Milestone to advance:** OD stable through at least three volume turnovers of yeast-extract-free medium.

After this milestone, the turbidostat continues running indefinitely as the maintenance mode for the established HOB culture.

---

## Stage 5 – Electrolysis-dependence confirmation

Stop electrolysis. Continue CO₂ sparging and turbidostat operation unchanged. Confirm electrolysis has stopped by measuring current draw with the multimeter – it should drop to near zero.

If OD declines over subsequent readings and does not recover until electrolysis is restored, the culture is electrolysis-dependent. Restore electrolysis and confirm OD recovers.

**What this confirms:** The dominant organisms require electrolytically produced H₂ to grow. Obligate heterotrophs are absent or non-dominant.

**What this cannot confirm without sequencing:** Obligate chemolithotrophs and mixotrophs are not distinguishable by this protocol. Some facultative HOB (e.g. *Hydrogenophaga*, *Achromobacter*) can persist on trace organics even after washout. Electrolysis-dependence is a functional criterion, not a purity criterion – but for home-lab purposes it is the meaningful feasible endpoint.

---

## References

- Givirovskiy et al. (2019) https://doi.org/10.3390/en12101904
- Pous et al. (2022) https://doi.org/10.1016/j.biteb.2022.101010
- Pous et al. (2023) https://doi.org/10.1016/j.jece.2023.111550
- Rovira-Alsina et al. (2025a) https://doi.org/10.1016/j.jpowsour.2025.236499
- Rovira-Alsina et al. (2025b, preprint) https://doi.org/10.2139/ssrn.5457298
- Yang et al. (2021) https://doi.org/10.1016/j.jclepro.2021.125921

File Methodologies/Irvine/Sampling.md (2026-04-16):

# Irvine River HOB Enrichment – Sampling

Field sampling protocol for collecting inoculum from the Irvine River for HOB enrichment using the [AEP0.1](https://github.com/amy-bo/electroPioreactor) electroPioreactor.

---

## Equipment and materials checklist

Before starting, confirm the following are available and functional:

- AEP0.1 initially set up at base - see [Enrichment.md](Enrichment.md)
- Clean centrifuge tubes (scalded with boiling water)
- 12V battery and leads (optional – see field pre-conditioning below)

---

## Sampling at the Irvine River

Sample from the inside bank. Target slow-flowing margins where fine sediment accumulates — pools behind rocks, inside bends, or backwater eddies where organic matter collects. The target community is at the oxic-anoxic interface where H₂ produced by anaerobes in the sediment diffuses upward into oxygenated water — this is where HOB naturally concentrate. In a river, this interface is typically in the top few centimetres of accumulated fine sediment in depositional zones, not in fast-flowing gravel beds.

Take a few centimetres of interface sediment and ~200 mL of overlying water from the same location. Avoid deep sediment, which will be dominated by methanogens and sulphate reducers.

Keep samples cool and dark during transport and process within 4 hours.

Transfer a portion of sediment to fill a clean centrifuge tube. Label with location, GPS coordinates, date, time, sampler name and sample ID matching the enrichment inoculum. Place in freezer on return and store until required for DNA extraction. No preservative is necessary for frozen samples; freezing prevents further community shift between sampling and analysis. This archive allows retrospective 16S rRNA sequencing of the source community for comparison against any enrichment culture derived from the matched inoculum. Samples remain viable for years in a domestic freezer (-18°C) and indefinitely at -80°C.

---

### Optional field pre-conditioning

If a 12V battery is available at the sampling site, the AEP0.1 can be run with river water as the initial electrolyte, with a CO₂ sparge before departure and again on return. Pre-conditioning the community to electrolysis conditions before lab enrichment improves reproducibility of subsequent community development (Pagaling et al., 2014). The practical risks — electrolyte spillage, vibration disrupting electrode contacts, and difficulty maintaining temperature during transit — should be weighed against the benefits. If conditions are calm and the reactor can be secured safely, it is worth doing; otherwise process the sample at home promptly.

---

## References

- Pagaling et al. (2014) https://doi.org/10.1038/ismej.2013.150

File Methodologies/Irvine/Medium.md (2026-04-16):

# Irvine River HOB Enrichment – Medium

Medium for HOB enrichment using the [AEP0.1](https://github.com/amy-bo/electroPioreactor) electroPioreactor.

---

## MC02 medium (provided by Edinburgh)

The medium is [MC02](https://github.com/amy-bo/electroPioreactor/tree/main/Media), prepared and provided by Bingqiao of Edinburgh University's Chris French Lab. It arrives as three bottles:

| Bottle | Contents | Dose per litre final medium |
|---|---|---|
| Mesonutrients | Na₂HPO₄, NaH₂PO₄·2H₂O, K₂SO₄, CaSO₄·2H₂O, MgSO₄·7H₂O, (NH₄)₂SO₄ | base solution |
| Iron solution | FeSO₄·7H₂O in 0.2 M H₂SO₄ | 3.40 mL |
| Mineral solution | Na₂MoO₄·2H₂O, ZnSO₄·7H₂O, MnSO₄·H₂O, CuSO₄·5H₂O, NiSO₄·6H₂O, CoSO₄·7H₂O in 0.2 M H₂SO₄ | 0.050 mL |

Combine per the dosing above. The resulting medium gives a phosphate buffer molarity of ~40 mM and a conductivity of ~6.1 mS/cm, consistent with Sydow et al. (2017) optimal medium. See [Media/README.md](../../Media/README.md) for full formulation details and rationale.

### Storage

Store iron and mineral solution bottles in amber bottles at 4°C. Purge iron solution headspace with an inert gas (N₂ or Ar) or CO₂ after each use. Remake if the iron solution turns yellow-brown or precipitate appears. See [Media/README.md](../../Media/README.md) for expected shelf life.

---

## Yeast extract (Stage 4 only)

1.0 g/L, prepared as a separate stock in distilled water and pressure-cooked before use. Do not include in Stages 2–3.

---

## NaHCO₃ (optional)

0.10 g/L, added directly to the medium. In a CO₂-sparged reactor, dissolved inorganic carbon is replenished continuously by sparging and NaHCO₃ is not needed during normal operation. Include it if the reactor will be run without sparging for any period, as it provides an inorganic carbon reserve at startup.

---

## Conductivity supplement (optional, for future optimisation)

Givirovskiy et al. (2019) add 5.45 g/L Na₂SO₄ to increase medium conductivity and reduce ohmic losses during electrolysis. This may materially help reduce ohmic constraints depending on current density and electrode geometry, and could be worth investigating once baseline enrichment is established. Not recommended for first enrichment attempts; record baseline conductivity and voltage first.

---

## References

- Givirovskiy et al. (2019) https://doi.org/10.3390/en12101904
- Sydow et al. (2017) https://doi.org/10.1002/elsc.201600252

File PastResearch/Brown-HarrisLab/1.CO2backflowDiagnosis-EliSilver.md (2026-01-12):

Martin Currie of AMYBO reported [an inexplicable backflow of electroPioreactor broth up the CO2 sparging tube between periods of sparging](https://forum.amybo.org/t/co2-sparger-drawback/52).

Eli Silver of [Brown's Harris Lab](https://sites.brown.edu/harrislab/) was initially unable to replicate the issue using water and a similar valve.  They procured an FZone regulator, as used by Martin, able to test with the FZone regulator and valve hooked up to their CO2 tank. This time he saw a backflow! 

The FZone solenoid valve, it turns out, does not have a vent. When the solenoid is open it connects the regulator to the needle valve. When closed it simply blocks the pathway between the two. Our other solenoid valve that on the outside looks very similar has some slight differences internally which I attempted to sketch out. The parts are actually interchangeable between the two valves, that's how similar they are. 
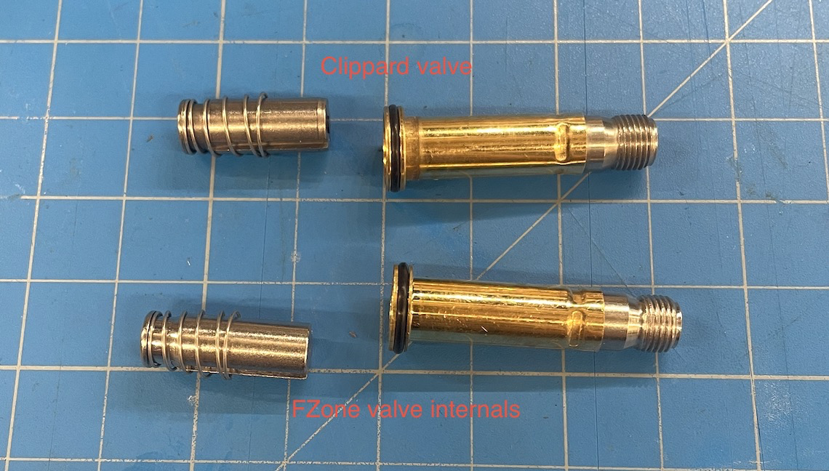
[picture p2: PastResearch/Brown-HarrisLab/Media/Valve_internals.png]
Valve internals

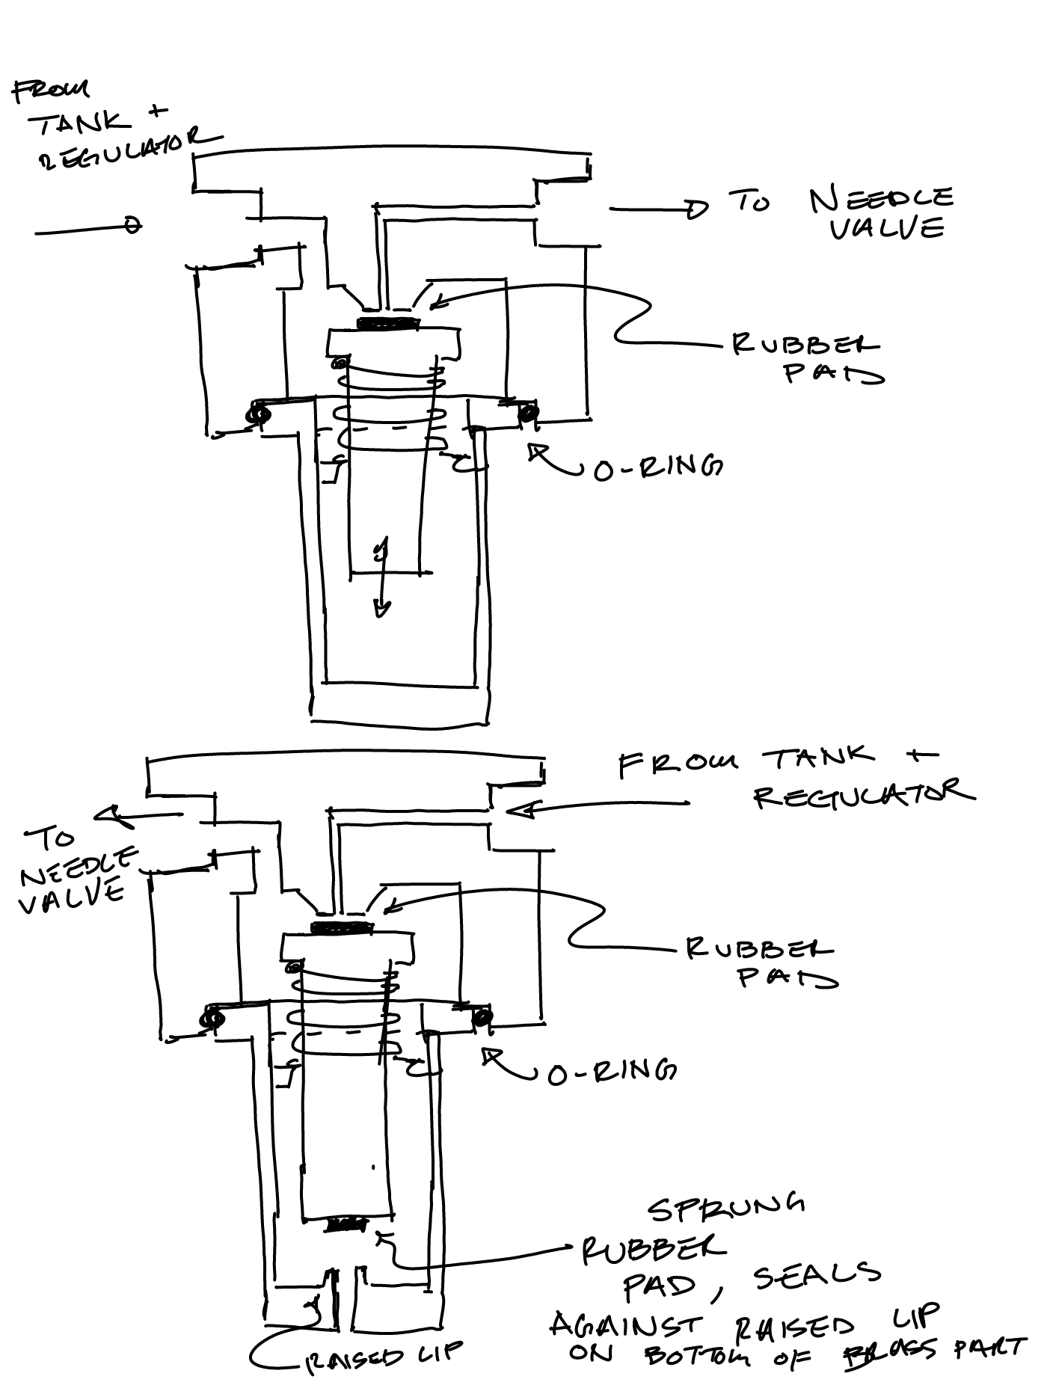
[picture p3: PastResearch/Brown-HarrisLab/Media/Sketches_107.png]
Sketches


What Eli believes is happening is once you purge CO2 through the system and turn off the solenoid, there is trapped gas between the valve and the cell culture. This gas is pure CO2 since it came right out of the bottle and displaced any air in the tubing. Since CO2 is highly soluble in water, gas trapped between the valve and the culture begins to dissolve. This reduces the volume of gas in the tube, reducing the pressure and drawing the culture up towards the valve. The water does not quickly saturate with CO2 because excess CO2(l) will turn back into CO2(g) at the air/water interface in the vial, which just allows the CO2 in the tube to continue dissolving.

To test this, Eli used their solenoid valve but plugged the vent. With no vent, he immediately saw backflow. With the vent open, the tube from the regulator to the culture is no longer sealed at the other so as CO2 dissolves it draws air in through the vent. Sure enough, he did not see any backflow with the vented valve. 

Next steps: 
The most straightforward solution would be to look for a solenoid valve with a vent. I haven't done any product research on this, but I imagine we can find a similarly priced valve with a vent. 

[2. Backflow testing with revised components - Eli Silver.md](2.BackflowTestingWithRevisedComponents-EliSilver.md)

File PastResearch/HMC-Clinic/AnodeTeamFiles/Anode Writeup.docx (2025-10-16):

The team used the potentiostat to determine how effectively the materials could conduct current for water electrolysis. The list below shows each anode-cathode pair that was tested in the potentiostat.

- Nickel - Nickel
- Nickel - Stainless Steel
- Original Graphite (Pencil Lead) - Original Graphite
- Original Graphite - Stainless Steel
- New Graphite (pure graphite bars) - New Graphite
- New Graphite - Stainless Steel
- Platinum - Platinum
- Platinum - Stainless Steel

The potentiostat can only readout the current of each anode cathode pairing, but for our analysis, we wanted to see the current density of each pairing to normalize all our values by the surface area of the anode available for water electrolysis. To do this we simply divide the current by the anode’s surface area in solution. This surface area was calculated by marking on the anode where it touches the surface of the water. From there we measured both the length and diameter of the anode. In calculating the surface area, we assumed each anode was a perfect cylinder and made calculations with the standard areas of a cylinder. From these calculations, the results are depicted in the figure below.

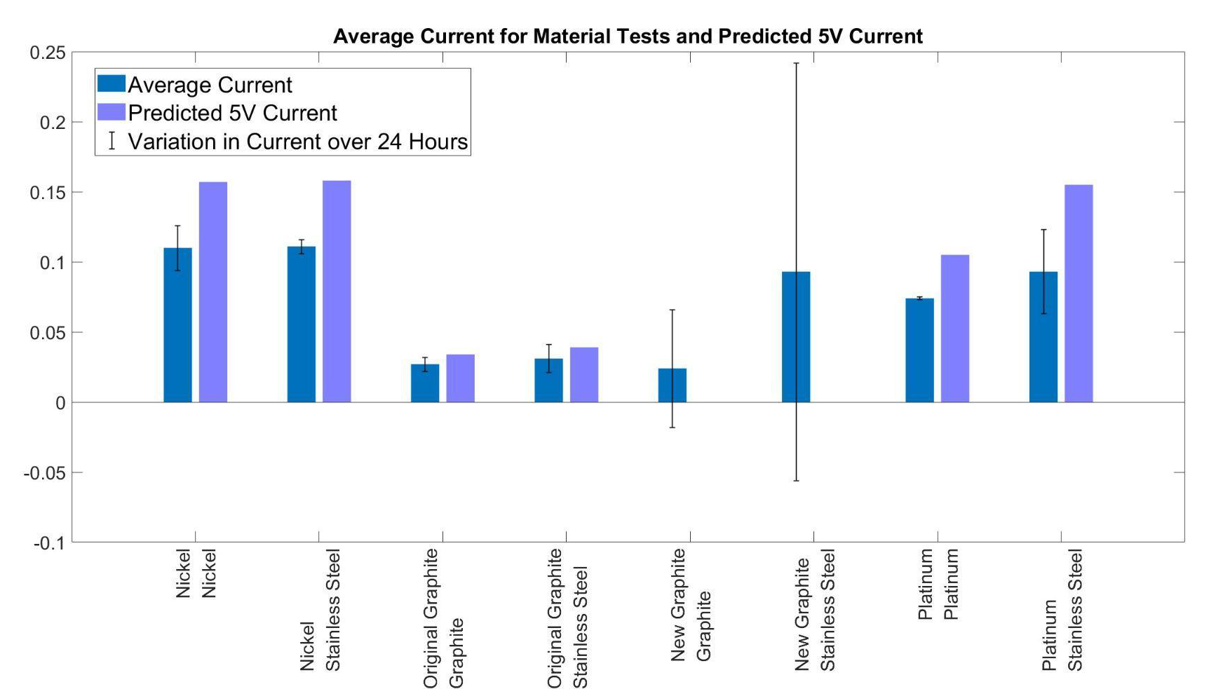
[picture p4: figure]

Results of current density tests on material pairings with standard deviation noted as the error bars. Lighter bars indicate a predicted 5V current density

In some of the findings, there is an additional value noting the “Predicted 5V current density.” Due to the potentiostat limitations, we could only read current up to 20mA, but some of our materials would reach higher values than that when a 5V voltage was applied. This would force us to reduce the voltage applied until the current reached back into a readable range. When the ion concentration, anode-cathode material, and anode-cathode distance are kept constant, however, we can assume that the resistance between the anode and cathode are equivalent and we can simply use Ohm’s law to determine what our results would have been at the 5V the Pioreactor will be supplying. These findings suggest that a nickel anode and stainless steel cathode outperform all other material pairings in current density, and exhibit low variation in current over time. While we would expect the platinum to perform the best, an interesting phenomena occurs on the surface of the nickel that may be allowing higher currents. The team, after consultation with chemistry professors, believes the nickel is reacting to form a specific nickel oxide that is improving the current density. While fouling usually impedes the current, the nickel tests will generally increase in current over the 24 hours of testing, pointing to the fouling being a conductive material as well.

Another factor considered for our anode analysis is the fouling that forms on the surface of each anode. Fouling is the buildup of material on the surface of the anode that is unwanted as it reduces the available surface area on the anode and reduces its ability to perform electrolysis. From our testing with the potentiostat, there are significant fouling issues with nickel and slight issues with the graphite. As seen below, fouling is present in nickel.

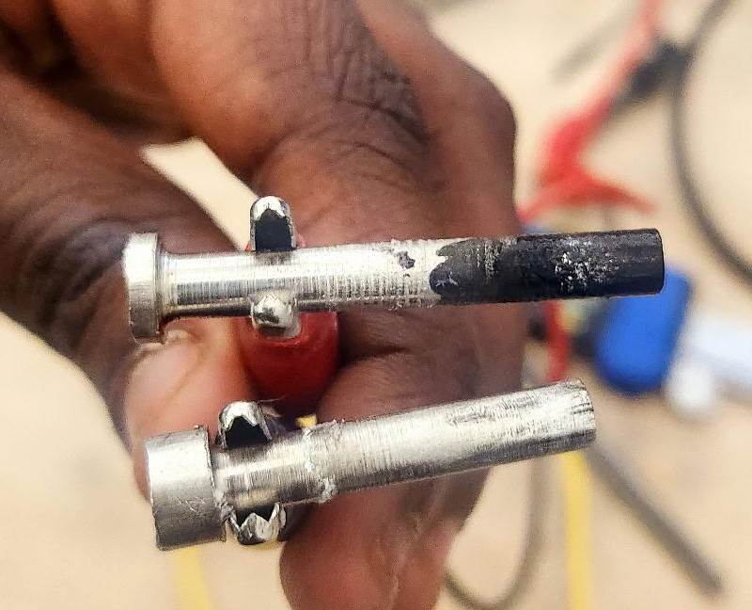
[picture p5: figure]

Visible fouling from Nickel Tests

The fouling that coats the nickel does not appear to be rust. The inky-black color to the substance and current increase seems to indicate there is another material forming. While there is little fouling in the case of pure graphite, there was a large amount of debris in solution from the graphite breaking off. Since this was much higher than the pencil graphite and the bar chart shows very little improvement between the two materials, further testing was not pursued with the pure graphite rods.

After understanding the current density of each material, we wanted to ensure that these materials support bacterial growth properly. While nickel-stainless steel has the highest current density, there may potentially be other factors that stunt the growth of bacteria and must be tested before that material can be selected as the best material for our use case. To test this, we use the optical density that the Pioreactor has onboard its system. Using the pioreactor, we can collect optical density data that tells us how much stuff we have in solution. Assuming all contamination measures were taken, the only substance we should have in solution is debris from the anode and HOBs. We account for the debris in solution by recording optical density measurements of our anode-cathode pairs without HOBs in solution. This gives us a baseline optical density including the debris that forms from our anode and can then be compared to our bacterial findings. The bacterial findings are below, while control tests are at the bottom of the document.

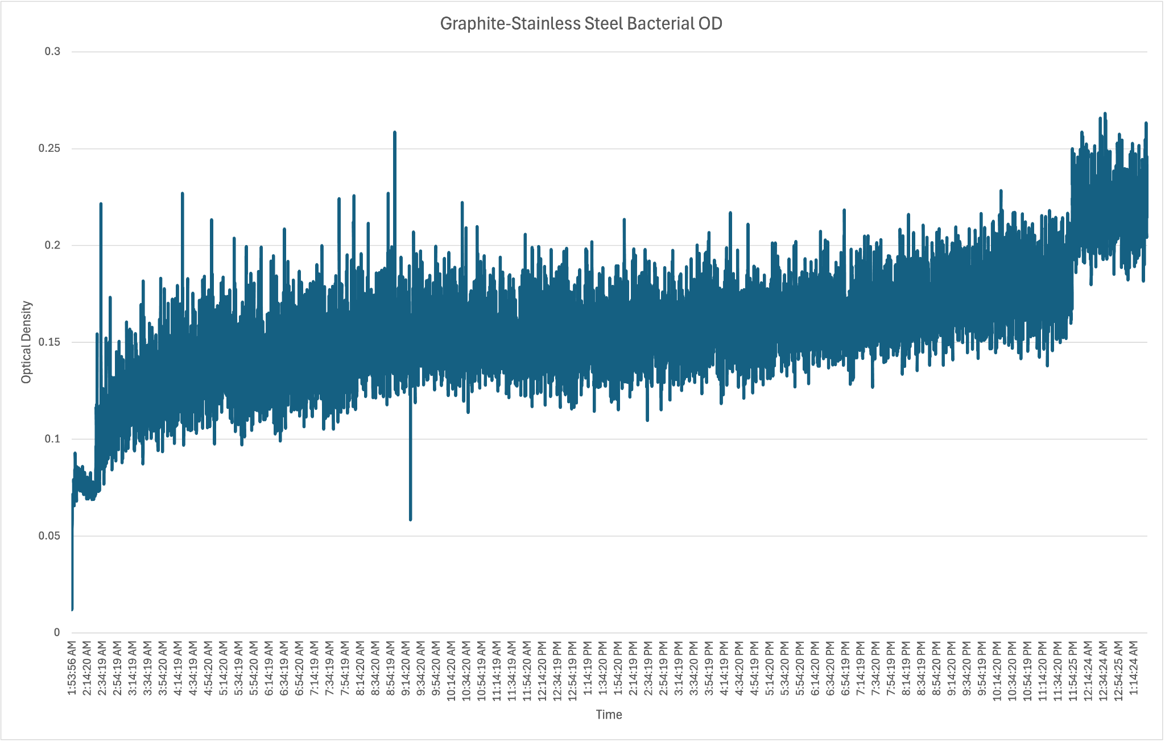
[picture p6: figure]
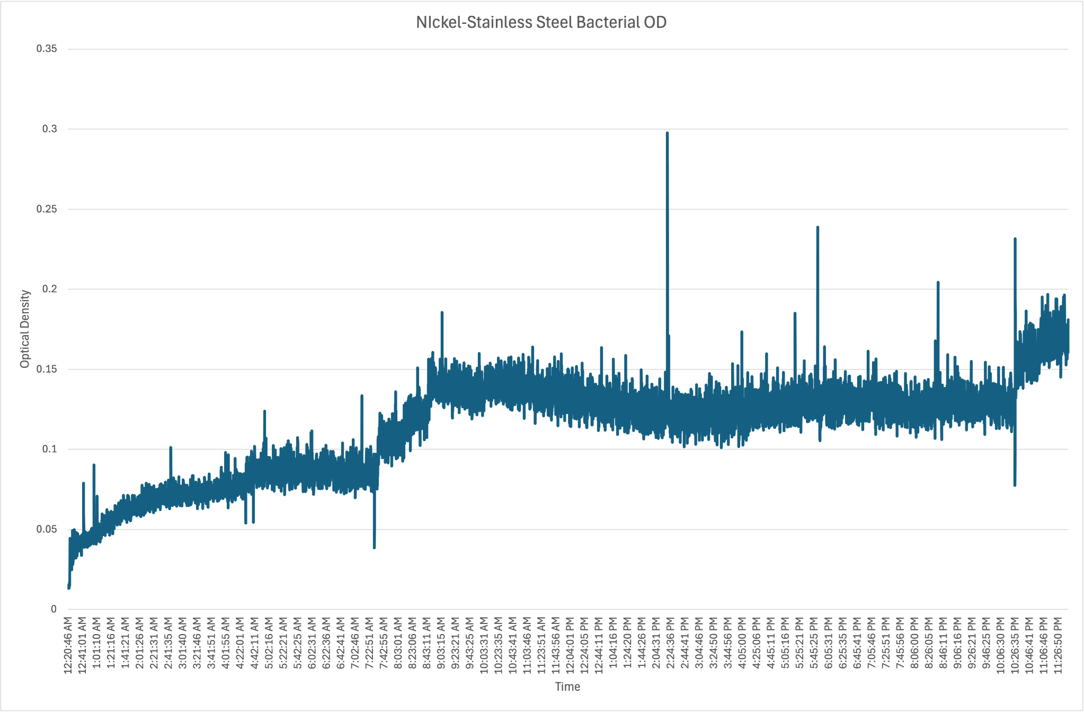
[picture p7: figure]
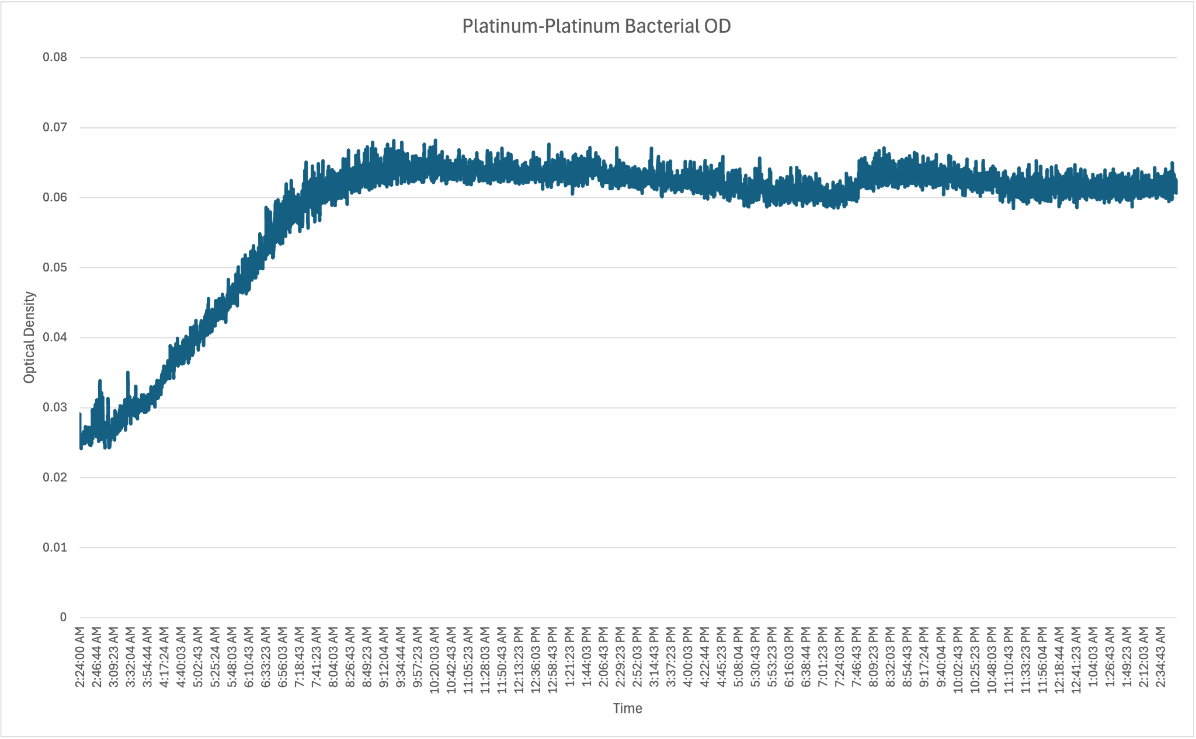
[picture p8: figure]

Optical density measurements for material pairings with bacteria in solution

To compare these results, it is more beneficial to pay attention to the rate of change of optical density between tests. From these results we can conclude that platinum-platinum has the highest optical density overall. While we currently have platinum-platinum selected as the best for optical density, it is important to compare these optical density results to those without bacteria. This allows for a better understanding of the rate of bacteria growth from the rate of change in optical density. From these results we can get a better understanding of what material promotes the most bacterial growth. In looking at the control data in Appendix D, we see that the nickel control test yields unrealistically high optical density readings for the control test that are not represented in the bacterial test. These values are attributed to the inky black substance that was formed by nickel. If this material were large enough to pass in front of the sensor, it would lead to data points that do not reflect the rest of the solution. This will need to be further investigated before we can make any claims about the best material to replace platinum in the system with full confidence. Additionally, bacterial growth curves were generated and are shown below. The growth rate, which is based on the optical density measurements, show that nickel is nearly as efficient in their ability to grow bacteria in solution as platinum plated titanium.

Future Recommendations

During testing with the potentiostat, metallic debris and fouling was observed in the solution. The anode subteam recommends further investigation into the composition of this debris to determine whether it is food-safe and to assess its overall impact on the current density performance. If the debris is found to be a contaminant, a standardized process for its removal should be explored. This includes assessing potential filtration methods that are specifically designed to target and remove the identified debris particles as well as an analysis on lower voltage in reducing the falloff while maintaining acceptable bacteria growth. Important considerations for filtration should include product availability, cost-effectiveness, and the ability to maintain solution quality.

Additionally, we recommend conducting further designing to find methods to increase surface area while achieving all other material objectives. This would involve researching easily manufacturable ways to increase surface area as well as considering how these designs may promote or prevent fouling on the surface of the anode.

Finally, in anticipation of commercial scaling, we suggest a thorough evaluation of the feasibility of electroplating the selected material combinations. This evaluation should consider the environmental impact of the process, health and safety risks to workers, the need for rigorous quality control of the metal finishes, and effective waste management strategies. Additionally, the high cost associated with sustainable electroplating methods may deter potential investors.

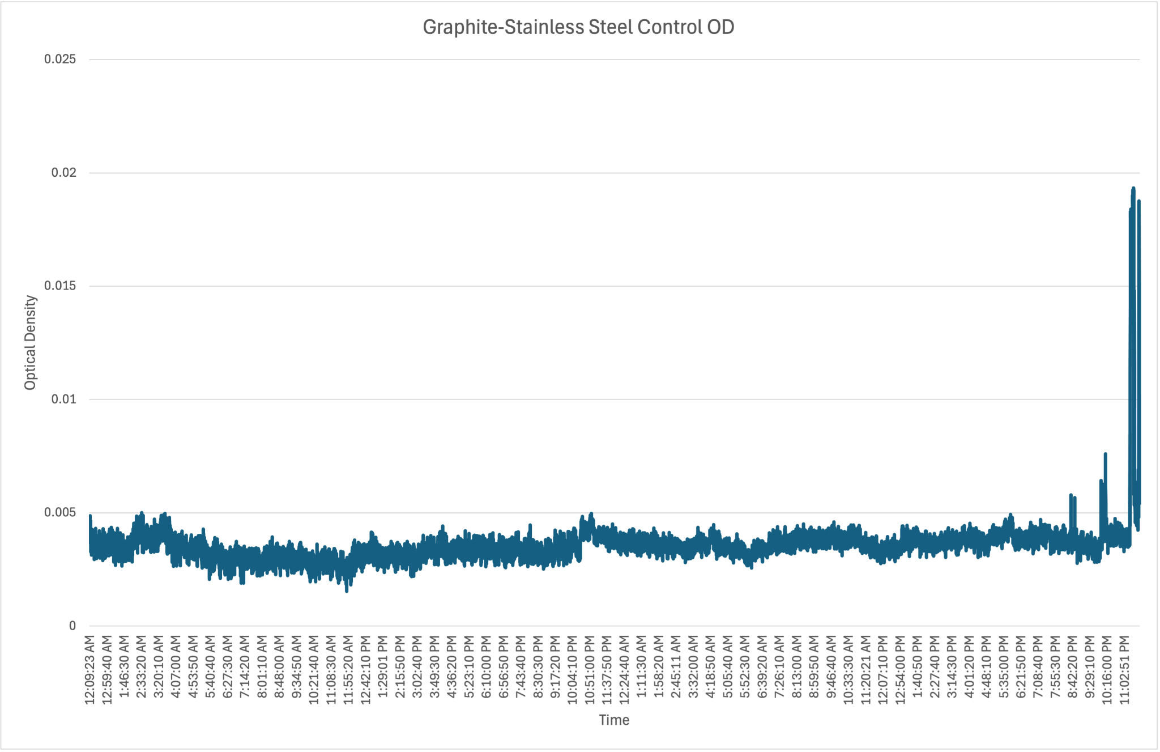
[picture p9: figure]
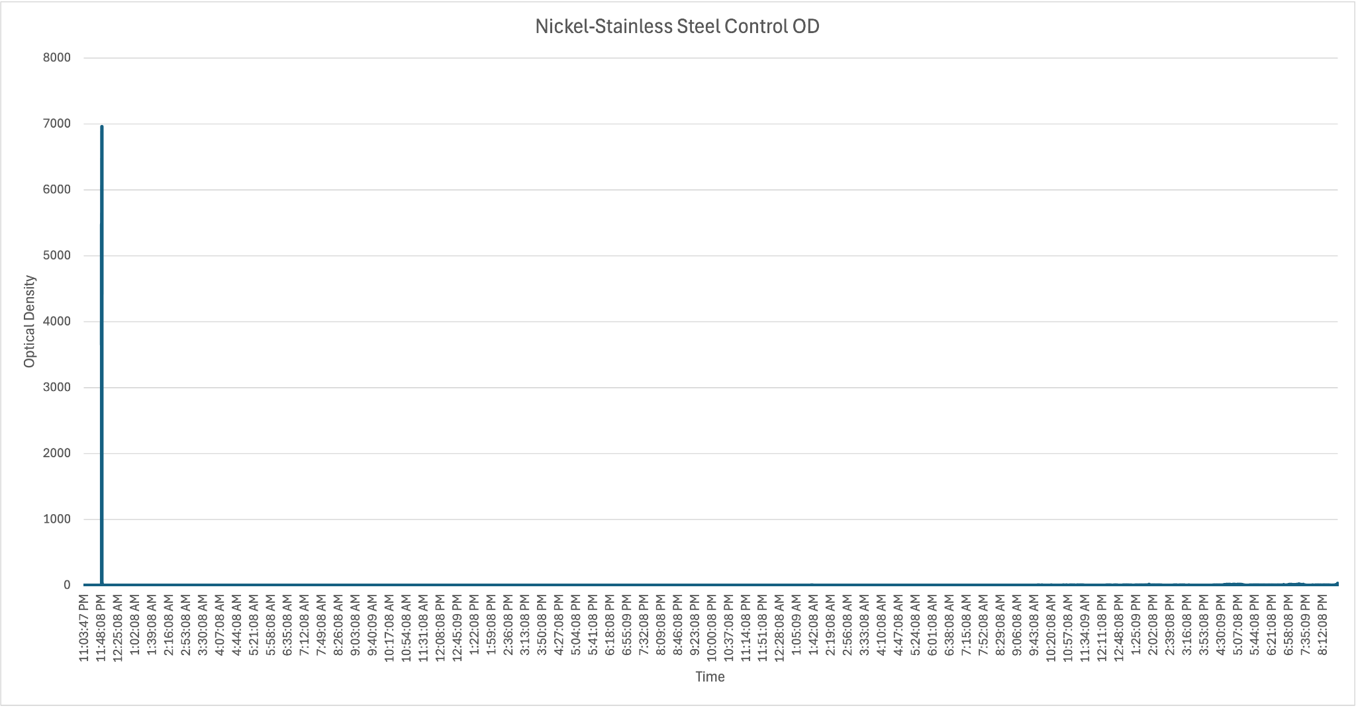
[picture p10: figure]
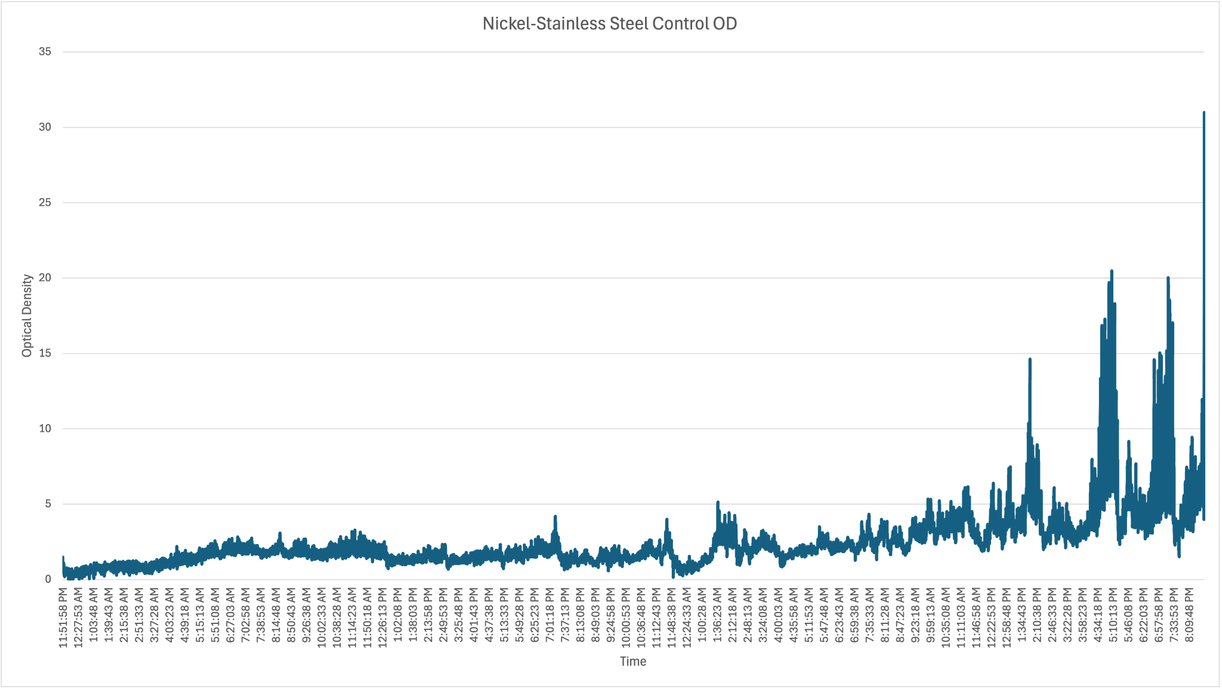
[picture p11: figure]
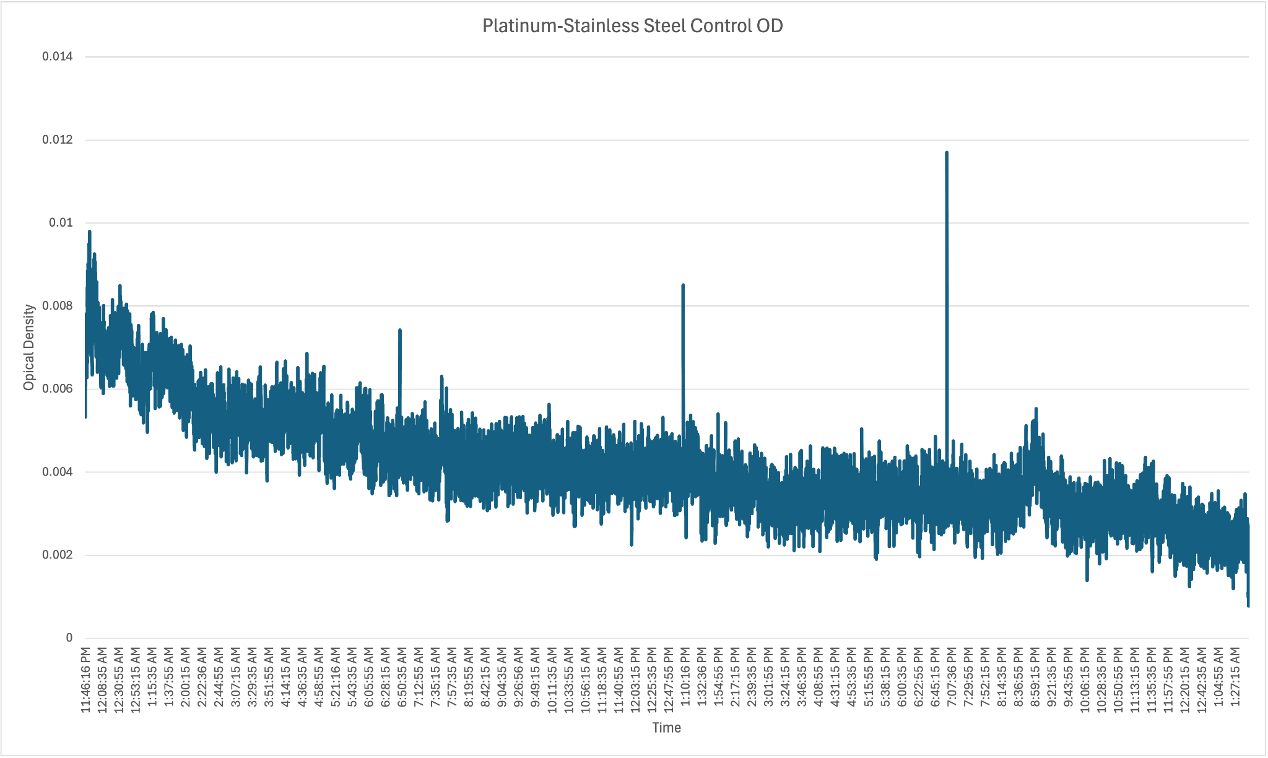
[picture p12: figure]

Control data for anode-cathode tests

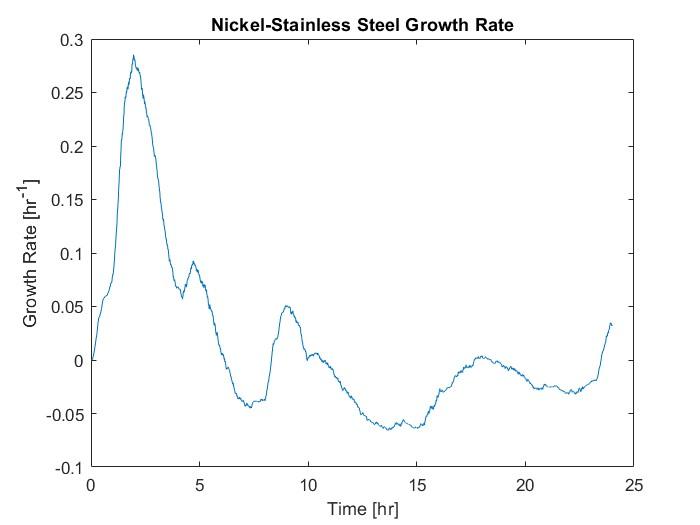
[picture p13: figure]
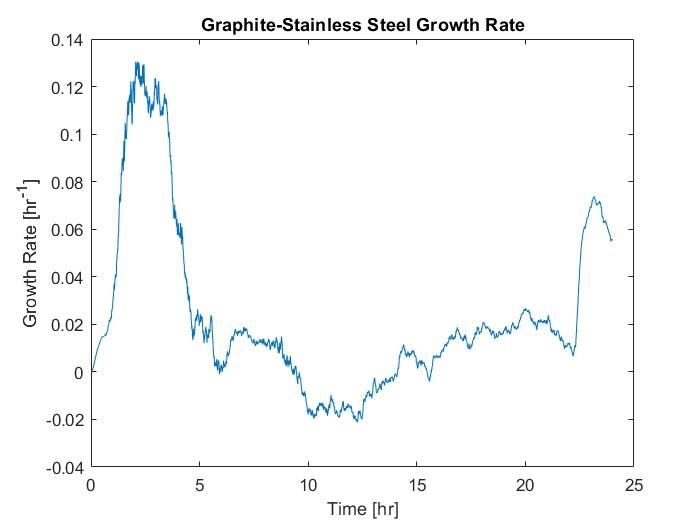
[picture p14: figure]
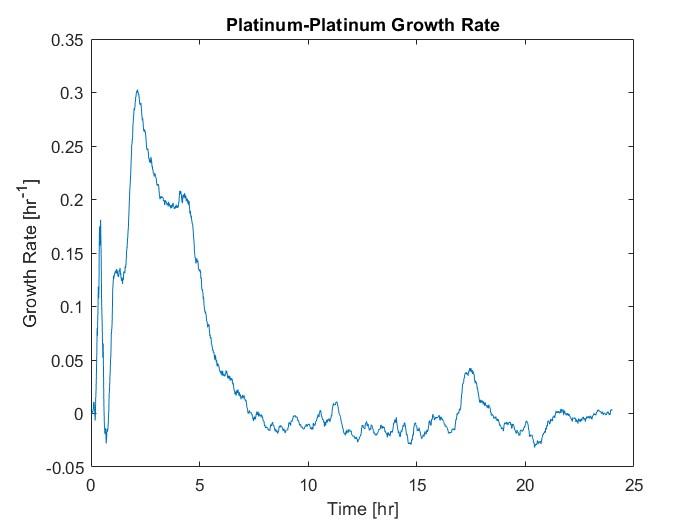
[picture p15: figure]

Growth curves for anode-cathode tests

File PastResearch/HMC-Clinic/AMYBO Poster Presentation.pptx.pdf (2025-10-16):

# Sustainable Protein for All

Madi Gonzalez (FTL), Tresselle Gatutha, August McIntosh-Lombardo (STL), Michelle Bazan (S), Sheridan Dorsey (F), Henry Heathwood (S), Alicia Krasner (F), Julia Kolt (S), Julien Luu (F) Advisor: Professor Phil Cha Liaisons: Dr. Martin Currie, Dr. Gerrit Niezen

35% of the worlds habitable land is taken up by livestock (Figure 1). Given biodiversity loss, population and carbon emissions growth, this is unsustainable. AMYBO aims to develop Sustainable Protein for All.

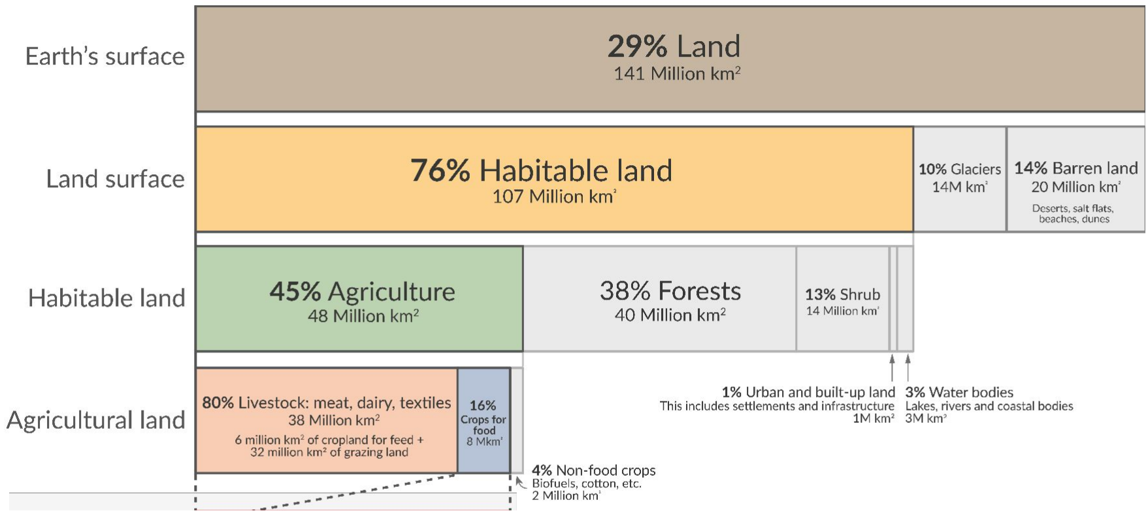
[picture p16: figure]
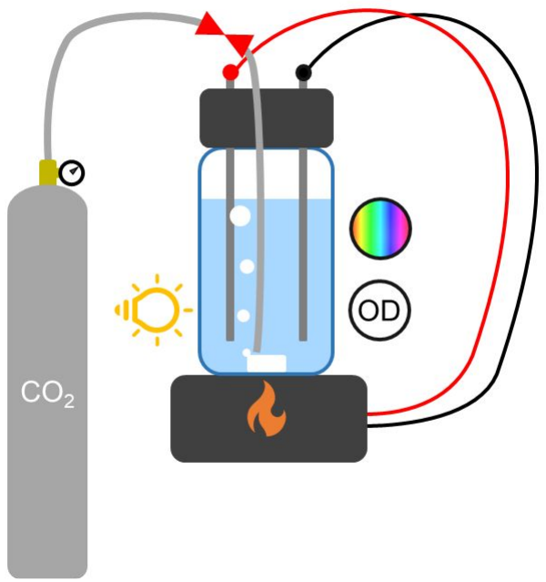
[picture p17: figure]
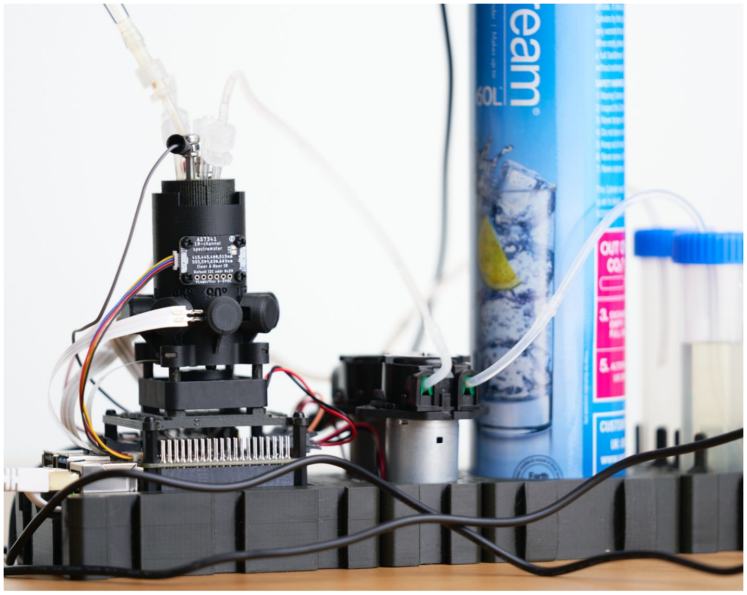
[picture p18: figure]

AMYBO is a non-profit, open source protein
fermentation | community. | They | develop
affordable bioreactors for researchers so they can contribute to the testing of hydrogen oxidizing bacteria as a novel protein source. The electroPioreactor (Figure 2) is an affordable bioreactor that performs water electrolysis and allows for the monitoring of bacterial growth. AMYBO's ultimate goal with the electroPioreactor is to allow anyone to produce sustainable protein from carbon dioxide and renewable energy.

HOB are strains of bacteria that can convert hydrogen into food using the chemical reaction equation as seen below.
4H2

+ O2

+ CO2

+ 0.24NH3

→

### CH1.68 N0.24 O0.46

+ 3.54H2O

The process can be facilitated using water electrolysis. Water molecules are split into their component parts. The HOB convert the oxygen and hydrogen, along with added CO2

and NH3
into ~70% Protein (nutritionally complete) biomass with water as a byproduct.
Company Introduction and Impact | What are Hydrogen Oxidizing Bacteria (HOB)?

## AMYBO’s Original Solution

Mixed Culture electroPioreactor v0.01 Setup (Figure 3):
- H

+
ions created via water electrolysis
- CO2

added through tube
- Both removes the excess O2

and
feeds bacteria
- NH3

added with other trace minerals
- Bacterial | growth | measured | using
optical density
- Anode and cathode are made with platinum plated titanium mesh and stainless steel, respectively
Current issues:
- Backflow when the CO2

input line is
shut off
- Anode material is expensive and not optimized

## Project Statement

AMYBO would like us to improve upon their current system by creating an open-source solenoid pinch valve that eliminates backflow, and optimizing the anode-cathode design and material. All solutions must be designed to be cost effective, reliable, reproducible, and self manufacturable.

Goal: Design a solenoid pinch valve to pinch 20cm 1/16" ID Silicone tubing
Constraints: Must be open source, controllable, eliminate backflow, normally closed

The valve team must pinch the 20cm 1/16" ID Silicone tubing used in the cap of the electroPioreactor as seen in Figure 4. The valve team utilized a lever to amplify the 20N spring force applied by the solenoid. The design can be seen in Figure 4. The solenoid is powered by the Pioreactor.

Testing

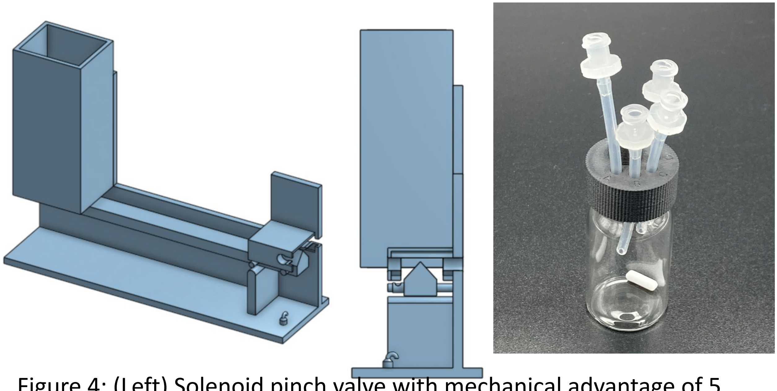
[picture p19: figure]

The valve, as pictured in Figure 5, pulls a maximum of 2.36A when powered with 11.31V. The image on the left pictures the valve open, and the image on the right shows the valve closed and unpowered. It is able to fully pinch the required 20cm 1/16" ID Silicone tubing used in the cap of the electroPioreactor.

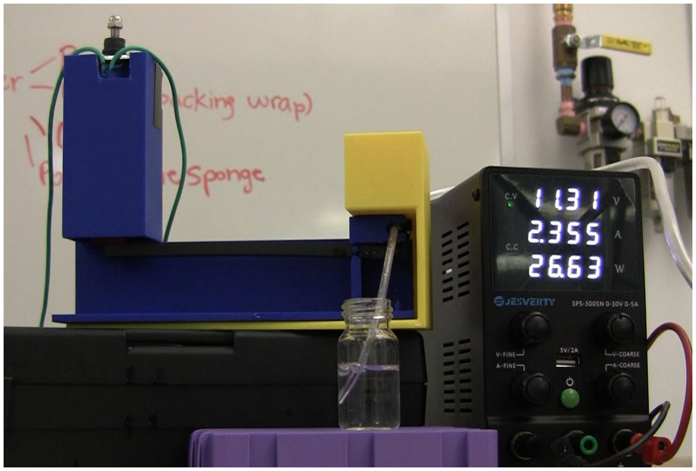
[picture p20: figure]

Conclusions and Future Work

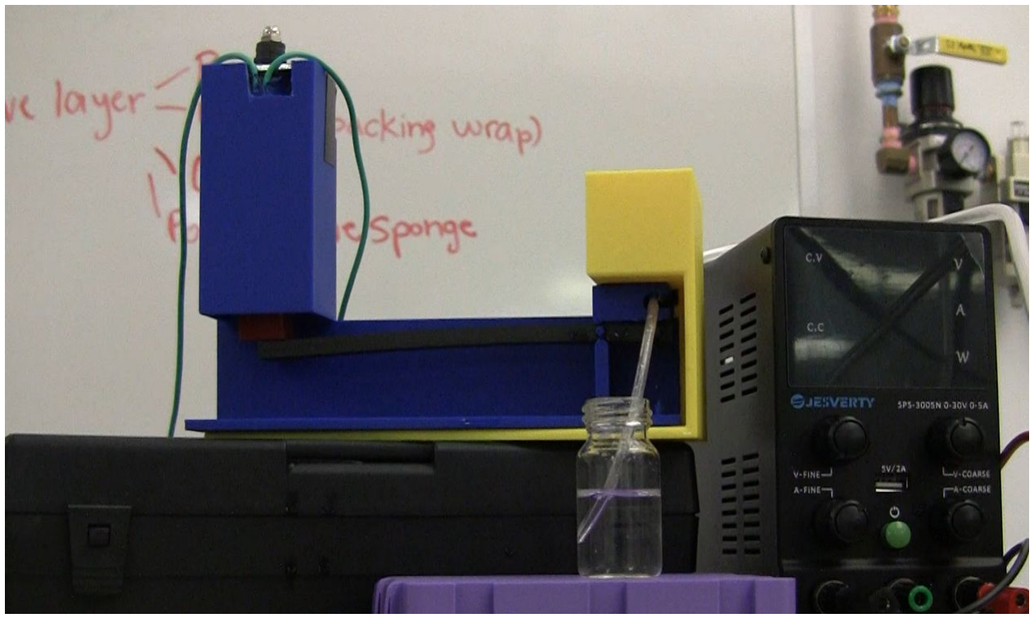
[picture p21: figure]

Valve is functional and controllable by the electroPioreactor. Future work involves adding support to the pinch mechanism so it stays aligned with the solenoid hat, reducing the footprint, and making the pinch support thinner to allow for better integration.

## Valve Subteam

Goal: Optimize anode and cathode for water electrolysis
Constraints: Cheaper and more easily manufacturable than platinum plated titanium mesh

The team tested nickel, stainless steel, and graphite rods for their ease of manufacture, low cost, and high current density. Additionally, platinum plated titanium rods were tested as controls. The team ran current tests using a potentiostat. The solution used was a mixture of deionized water and sodium bicarbonate. The results of these tests are shown in Figure 6.

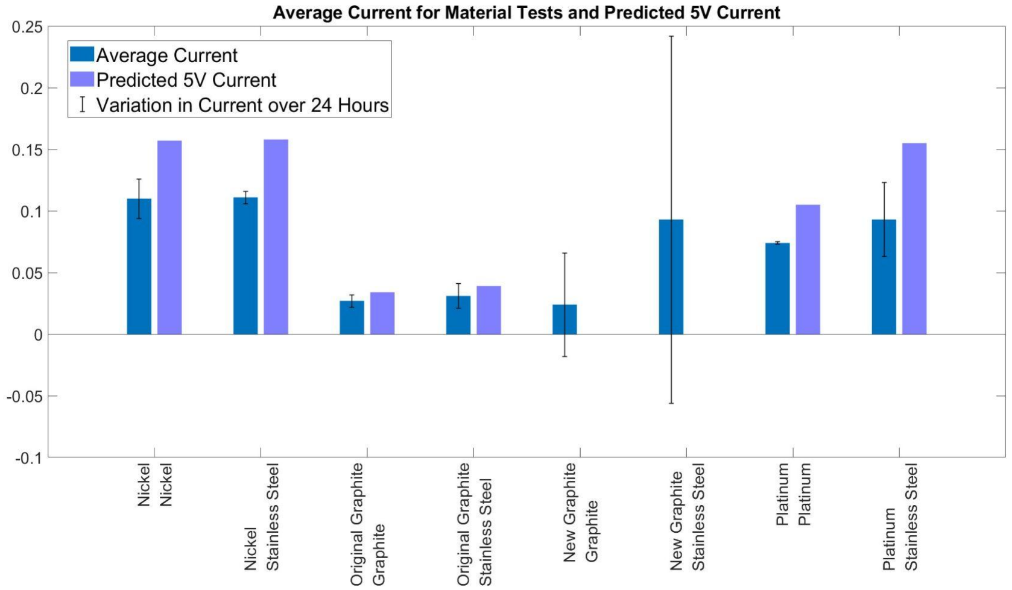
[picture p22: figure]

The team tested if the HOB would grow in solution with the selected materials. Implied growth rate results are shown in Figure 7. As we were not replacing growth media, relevant data is only of the exponential phase and highest implied growth rate reached. Importantly, we cannot be sure data is a reflection of bacterial growth as there was significant falloff from our anode and cathode. Therefore, we cannot make any concrete conclusions. Visual inspection of the vials after experimentation did show bacterial growth, which is promising.

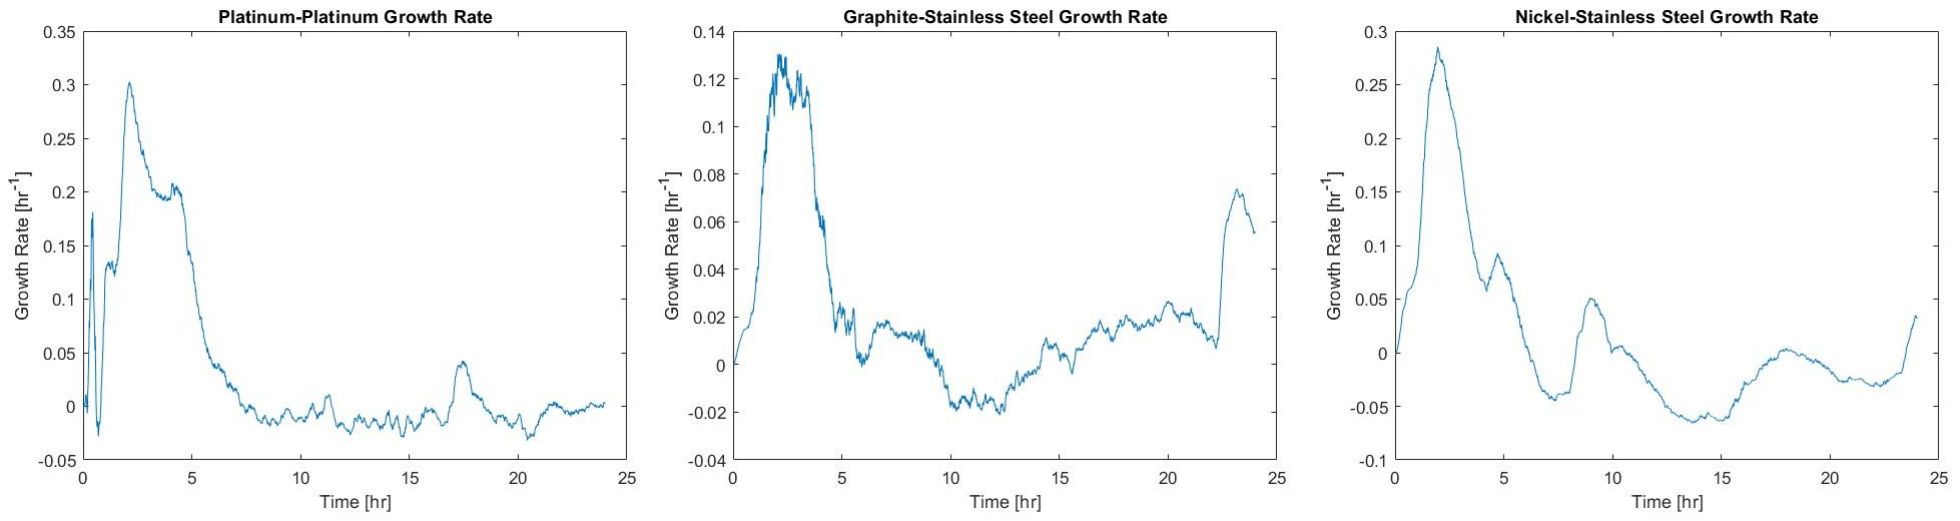
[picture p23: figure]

Conclusions and Future Work
Based on the data results, nickel-stainless steel is worth investigating further as it is easily manufacturable, cost effective, had high current density with little fluctuation in current over time, and the HOB had a high implied growth rate.
Other future work includes optimizing the anode for surface area and fouling.

## Anode Subteam

## Acknowledgements

The AMYBO clinic team would like to acknowledge the help provided by Professor Van Ryswyk, Professor Dato, Professor Stoebel, Drew Price, Professor Bahena, Professor Lape, Jacob Staimpel, Cam Davidson Pilon, Jenny Nguyen, Daniel Guerra, Lea Twicken, and Annalee Sendis

Figure 4: (Left) Solenoid pinch valve with mechanical advantage of 5 (Right) 20cm 1/16" ID Silicone tubing to be pinched

Figure 1: Breakdown of world’s habitable land by use from Our World in Data

Figure 3: AMYBO electroPioreactor setup Figure 2: electroPioreactor

Figure 5: (Left) Solenoid pinch valve open (Right) solenoid pinch valve closed

Figure 6: Current density test results

Figure 7: Implied growth rate results (Left) Platinum-Platinum (Middle) Graphite-Stainless Steel (Right) Nickel-Stainless Steel

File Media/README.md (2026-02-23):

# Medium for HOB fermentation with in-culture electrolysis

## Background

This document details our proposed total nutrients for hydrogen-oxidising bacteria (HOB) fermentation.  
Nutrients are broken down into:

1. Macronutrient gases,
2. Mesonutrient solution as per [Sydow et al. (2017)](https://doi.org/10.1002/elsc.201600252), and
3. Our modified two-bottle Micronutrient solution.

We require an optimal nutrient solution for HOB fermentation that is also appropriate to use as an electrolyte for in-culture electrolysis to generate hydrogen and oxygen for HOB. The solution should be relatively easy to formulate, and its trace elements component should have a long shelf life.

While many standard and optimised formulations exist for general HOB fermentation, most contain compounds that would have deleterious consequences when subject to electrolysis, for example, evolving ammonia and chlorine, forming hypochlorous acid, etc.

[LiteratureMedia.md](LiteratureMedia.md) discusses over 10 papers describing media used specifically for HOB fermentation with in-culture electrolysis.  Of these it explains the selection of [Sydow et al. (2017)](https://doi.org/10.1002/elsc.201600252)'s 'Optimal Medium' as the basis for our media formulation. [MediaFormulation.md](MediaFormulation.md) goes on to explain how we derived the longer shelf life trace element solution below from this.

## Macronutrients

| Component | Formula | Source |
|---|---|---|
| Hydrogen | H₂ | electrolysis of water |
| Oxygen | O₂ | electrolysis of water |
| Carbon Dioxide | CO₂ | sparged from SodaStream cylinder |

Hydrogen should be the limiting nutrient, so its production will be maximised without causing excessive electrode degradation.

Oxygen is produced to excess at a rate that will cause accumulation that limits electrolysis unless purged by carbon dioxide.

The carbon dioxide purge rate will be set with this, and hydrogen combustion risk reduction, in mind.  [See calculations](https://docs.google.com/spreadsheets/d/1Aeqz_CXZz-brBo-cXe8sFfjbX8h42vEcrhPH9bGLhIA/edit?gid=0#gid=0).

## Mesonutrients

[Sydow et al. (2017)'s Supporting Information](https://analyticalsciencejournals.onlinelibrary.wiley.com/action/downloadSupplement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) Table S1 gives their 'Optimal Medium' as:

| Component | Formula | Concentration (g/L) |
|---|---|---|
| Disodium hydrogen phosphate | Na₂HPO₄ | 2.895 |
| Sodium dihydrogen phosphate dihydrate | NaH₂PO₄·2H₂O | 3.060 |
| Potassium sulfate | K₂SO₄ | 0.170 |
| Calcium sulfate dihydrate | CaSO₄·2H₂O | 0.097 |
| Magnesium sulfate heptahydrate | MgSO₄·7H₂O | 0.800 |
| Ammonium sulfate | (NH₄)₂SO₄ | 0.943 |

With trace elements given in 'Sydow Trace Nutrients in final media' below.

## Micronutrients / Trace Element Solution

Our two-bottle trace element solution, [modified](MediaFormulation.md) from [Sydow et al. (2017)](https://doi.org/10.1002/elsc.201600252) is made up in batches, at concentrations such that 0.050 mL of Mineral Solution and 3.40 mL of Iron Solution are added per 1.000 L of Mesonutrient solution.

### Mineral Solution

| Component | Formula | Concentration (g/L in 0.2 M H₂SO₄) |
|---|---|---|
| Sodium molybdate dihydrate | Na₂MoO₄·2H₂O | 1.8 |
| Zinc sulfate heptahydrate | ZnSO₄·7H₂O | 2.4 |
| Manganese(II) sulfate monohydrate | MnSO₄·H₂O | 2.4 |
| Copper(II) sulfate pentahydrate | CuSO₄·5H₂O | 0.48 |
| Nickel(II) sulfate hexahydrate | NiSO₄·6H₂O | 1.5 |
| Cobalt(II) sulfate heptahydrate | CoSO₄·7H₂O | 0.0402 |

### Iron Solution

| Component | Formula | Concentration (g/L in 0.2 M H₂SO₄) |
|---|---|---|
| Iron(II) sulfate heptahydrate | FeSO₄·7H₂O | 15.0 |

### Storage and shelf life

We anticipate that, if refrigerated at 4 °C in amber bottles (kept dark), the mineral solution may remain stable for multiple years (target >5 years), and the acidified iron solution for nearly as long (target >3 years) if the bottle headspace is purged with an inert gas (e.g. N₂ or Ar) after opening.

### Sydow Trace Elements in final media

| Component | Formula | Concentration (g/L) |
|---|---|---|
| Iron(II) sulfate heptahydrate | FeSO₄·7H₂O | 0.051 |
| Manganese(II) sulfate monohydrate | MnSO₄·H₂O | 1.2 ×10⁻⁴ |
| Zinc sulfate heptahydrate | ZnSO₄·7H₂O | 1.2 ×10⁻⁴ |
| Copper(II) sulfate pentahydrate | CuSO₄·5H₂O | 2.4 ×10⁻⁵ |
| Sodium molybdate dihydrate | Na₂MoO₄·2H₂O | 9 ×10⁻⁵ |
| Nickel(II) sulfate hexahydrate | NiSO₄·6H₂O | 7.5 ×10⁻⁵ |
| Cobalt(II) sulfate heptahydrate | CoSO₄·7H₂O | 2.01 ×10⁻⁶ |

## Final Medium

[Sydow et al. (2017)'s Supporting Information](https://analyticalsciencejournals.onlinelibrary.wiley.com/action/downloadSupplement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) S1 gives the following elemental composition:

| Element | Symbol | Concentration (g/L) |
|---|---|---|
| Sodium | Na | 1.389 |
| Potassium | K | 76 ×10⁻³ |
| Nitrogen | N | 0.2 |
| Magnesium | Mg | 79 ×10⁻³ |
| Calcium | Ca | 22.6 ×10⁻³ |
| Iron | Fe | 10 ×10⁻³ |
| Nickel | Ni | _2.7 ×10⁻⁵ <sup>*</sup>_ |
| Copper | Cu | 6.1 ×10⁻⁶ |
| Chromium | Cr | - |
| Cobalt | Co | 4.2 ×10⁻⁷ |
| Manganese | Mn | 3.9 ×10⁻⁵ |
| Zinc | Zn | 2.73 ×10⁻⁵ |
| Phosphorus | P | 1.24 |
| Sulphur | S | 0.39 |
| Molybdenum | Mo | 3.6 ×10⁻⁵ |
| Chlorine | Cl | - |
| Carbon | C | - |

_<sup>*</sup>_ We believe that [Sydow et al. (2017)'s Supporting Information](https://analyticalsciencejournals.onlinelibrary.wiley.com/action/downloadSupplement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)'s calculation has carried forward the Ni₂SO₄·6H₂O typo and the actual concentration of Ni would be 1.67 ×10⁻⁵. While we don't anticipate this impacting their results further investigation may be prudent.

Their media was also supplied with 200 μg/mL kanamycin for pEG7c maintenance, it is assumed that this will not be required with our strains.

They also note the following:

| Parameter | Value |
|---|---|
| Buffer molarity | 40 mM |
| Conductivity | 6.1 mS/cm |

And that the solution has no carbon species, is not pH stable, but is electrochemically stable.

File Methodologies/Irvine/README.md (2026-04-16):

# HOB Enrichment Methodology – Irvine River

A protocol for enriching hydrogen-oxidising bacteria (HOB) from the Irvine River using the [AEP0.1.1](https://github.com/amy-bo/electroPioreactor) electroPioreactor, with MC02 medium provided by Bingqiao of Edinburgh University's Chris French Lab. Adapted for this sampling site and pre-made medium.

| Document | Contents |
|---|---|
| [Medium.md](Medium.md) | MC02 medium as provided by Edinburgh (three-bottle system), plus optional additives |
| [Sampling.md](Sampling.md) | Equipment checklist, field sampling procedure at the Irvine River |
| [Enrichment.md](Enrichment.md) | Lab enrichment stages 2–5: initial HOB selection, serial transfer, yeast extract boost, electrolysis-dependence confirmation |

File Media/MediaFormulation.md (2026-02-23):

# Media for HOB fermentation with in-culture electrolysis

## Literature

We describe in [LiteratureMedia.md](LiteratureMedia.md) why we selected [Sydow et al. (2017)](https://doi.org/10.1002/elsc.201600252) as the basis of our formulation and its reported shelf-life issue.

## [Sydow et al. (2017)](https://doi.org/10.1002/elsc.201600252) trace-element stock solution

| Component | Formula | Concentration (g/L in 0.1 M HCl) |
|---|---|---|
| Iron(II) sulfate heptahydrate | FeSO₄·7H₂O | 15.0 |
| Manganese(II) sulfate monohydrate | MnSO₄·H₂O | 2.4 |
| Zinc sulfate heptahydrate | ZnSO₄·7H₂O | 2.4 |
| Copper(II) sulfate pentahydrate | CuSO₄·5H₂O | 0.48 |
| Sodium molybdate dihydrate | Na₂MoO₄·2H₂O | 1.8 |
| Nickel(II) sulfate hexahydrate | NiSO₄·6H₂O | 1.5 |
| Cobalt(II) sulfate heptahydrate | CoSO₄·7H₂O | 0.0402 |

Sydow et al. (2017) list Ni₂SO₄·6H₂O in Table S1, which appears to be a typographical error. Nickel(II) sulfate hexahydrate (NiSO₄·6H₂O) is used here.

## Long shelf life split solution
In the presence of oxygen, at pH >1, Fe²⁺ oxidises rapidly to Fe³⁺ which hydrolyses and precipitates. Acidification of the solution should slow this. However:
1. Anhydrous HCl boils at −85 °C. Opening the bottle to withdraw solution will both introduce oxygen and allow HCl gas to escape.
2. Cu²⁺ can accelerate Fe²⁺ oxidation in acidic sulfate solution under oxidising conditions ([Wermink, et al](https://doi.org/10.1080/00986445.2018.1499017)).
3. Other metals are likely to co-precipitate onto/with freshly formed Fe(III) hydroxide/oxyhydroxide ([Gyliene, et al](https://sterc.org/pdf/p1196i.pdf)).

This explains the colour change (aqueous Fe²⁺ is green, Fe³⁺ is yellow/red/brown) and precipitation seen at the Holtmann lab. It is consistent with Fe²⁺ oxidising to Fe³⁺ and Fe³⁺ forming ferric hydroxide/oxyhydroxide, which can also remove other trace metals from solution.

Segregating iron from the other trace minerals will mean that if it precipitates, only the iron solution needs to be remade.  It can also be made at lower pH, which should reduce precipitation.  H₂SO₄ boils at over 300°C, so it will be less likely to gas off.  It also has a lower pH given the same concentration, and we intend to increase the acid concentration to 0.2 M.

## Composition

Given the success reported with use of the [Sydow et al. (2017)](https://doi.org/10.1002/elsc.201600252) minimal medium, we intend to stay as close to its formulation as possible while removing the final chlorides (in the HCl) and separating it into two solutions in order to increase shelf life.

We initially tried only acidifying the FeSO₄ and making the separate trace mineral solution in deionised water without pH adjustment, however this resulted in precipitation.  Addition of concentrated H₂SO₄ to bring the H₂SO₄ concentration to 0.1M redissolved the precipitate.  It was subsequently decided to change our trace mineral formulation protocol to dissolve the minerals in 0.2M H₂SO₄.

We may compare FeSO₄ stocks acidified with HCl versus H₂SO₄; thereafter we only intend to add more components if we have reason to suspect that they are specifically required by HOB of interest.

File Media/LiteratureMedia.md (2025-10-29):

# Literature on Media for HOB fermentation with in-culture electrolysis

## Literature found

The following papers have been [found](../Literature/README.md) which give media compositions for fermentation of hydrogen oxidising bacteria (HOB) using in-culture electrolysis.  We are not considering fermentation where H₂ is supplied from a source external to the culture, as we believe the impact of ionic strength on electrolysis is significant and that chlorides will also adversely impact HOB (through biocidal hypochlorous acid formation) and electrode impacts.  We have likewise excluded formulations for Photoelectroautotrophic growth and Microbial Electrochemical Recovery Cells.

### Original formulations

1. [Liu et al. (2016)](https://doi.org/10.1126/science.aaf5039) used a low‑ionic‑strength (~36 mM phosphate buffer) _R. eutropha_ medium and showed improved electrolysis performance at higher ionic strength (~108 mM phosphate buffer).
2. [Sydow et al. (2017)](https://doi.org/10.1002/elsc.201600252) proposed a low‑chloride, organic‑free minimal medium to enable fast electroautotrophic growth of _Cupriavidus necator_, reporting essentially zero lag phase, a high specific growth rate (~0.09 h⁻¹) and no observable electrode fouling under in‑culture electrolysis.
3. [Al Rowaihi et al. (2018)](https://doi.org/10.1371/journal.pone.0196079) customised nitrogen- and trace metal‑deprivation media specifically to drive PHB accumulation under stress rather than maximise growth.

### Modifications to [Sydow et al. (2017)](https://doi.org/10.1002/elsc.201600252)

1. [Stöckl et al. (2020)](https://doi.org/10.1002/cssc.202001235) increased buffer capacity to manage pH during formate utilization.
2. [Dinges et al. (2024)](https://doi.org/10.1002/cssc.202301721) varied K⁺ and Na⁺ ratios (0.2 M phosphate buffer) for improved coupled electro-formate/polyhydroxybutyrate (PHB) synthesis.
3. [Langsdorf et al. (2024)](https://doi.org/10.1016/j.jcou.2024.102800) detailed the minimal medium composition used for direct electroautotrophic PHB production using flue gas.

### Modifications to [Liu et al. (2016)](https://doi.org/10.1126/science.aaf5039)

1. [Feng et al. (2023)](https://doi.org/10.3389/fmicb.2023.1254451) modified the Liu et al. (2016) formulation by increasing phosphate buffer / ionic strength (e.g. 108 mM up to 180 mM KPi) to enrich halotolerant HOB for in‑culture electrolysis, and explicitly benchmarked their reactor and electrolyte against Liu et al. (2016).

### Modifications to [Matassa et al. (2016)](https://doi.org/10.1111/1751-7915.12369)

1. Pous et al. ([2022](http://doi.org/10.1016/j.biteb.2022.101010) and [2023](http://doi.org/10.1016/j.jece.2023.111550)) reduced ammonium content but retained chloride.

### Modifications to [Leibniz-Institut DSMZ growth medium number 81](https://www.dsmz.de/microorganisms/medium/pdf/DSMZ_Medium81.pdf)

1. [Givirovskiy et al. (2019)](https://doi.org/10.3390/en12101904) and [Ruuskanen et al. (2021)](https://doi.org/10.1016/j.jclepro.2020.123423) replaced major chloride compounds with sulfates; reduced ferric ammonium citrate; and added Na₂SO₄ to increase conductivity for hybrid biological-inorganic system scale-up.
2. [Nyyssölä et al. (2021)](https://doi.org/10.1021/acsfoodscitech.0c00129) replaced chlorides with sulfates, and included a wide array of vitamins for Gram-positive HOB.

### Patents

1. [Reed et al. (2015)](https://worldwide.espacenet.com/publicationDetails/biblio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).

## Selection of base formulation

Of the above [Sydow et al. (2017)](https://doi.org/10.1002/elsc.201600252), most of the papers modifying their formulation and [Al Rowaihi et al. (2018)](https://doi.org/10.1371/journal.pone.0196079) are explicitly chloride free.  Of these Al Rowaihi needed to maximize cellular stress as their main aim was PHB production, whereas Sydow, et al. aimed for rapid growth, requiring optimization for biological vitality.  Sydow et al's aims are therefore aligned with ours.

## Motivation for modification

### Shelf life

Prof. Dirk Holtmann was the corresponding author of [Sydow et al. (2017)](https://doi.org/10.1002/elsc.201600252). Personal communication with researchers in his current lab, who use the same formulation, indicated that the solution starts off blue then turns yellow within a couple of days, and starts to precipitate within a couple of weeks or months.  While it is beneficial for the Holtmann lab to maintain consistency between their experiments, we require media with longer shelf life.

### Omitted Components

[Sydow et al. (2017)](https://doi.org/10.1002/elsc.201600252) and papers based on their formulation omitted the following:

#### Boron

The vast majority of other formulations included boric acid (H₃BO₃).

#### Vanadium

Some DSMZ papers included Sodium Metavanadate (NaVO₃) or Ammonium metavanadate (NH₄VO₃).

#### Chelating agents

In order to make the medium free of carbon sources, chelating agents (which likely prevented precipitation hence lengthening shelf life) were omitted by [Sydow et al.](https://doi.org/10.1002/elsc.201600252).

#### Chlorides

[Sydow et al.](https://doi.org/10.1002/elsc.201600252) sought to be chloride-free, only using HCl to acidify the trace mineral solution.  Nobody at the Holtmann lab could recall why they didn't use H₂SO₄ in order to go completely chloride‑free.

#### Vitamins and Organic Cofactors

Some media, particularly those designed for specific strains or based on comprehensive formulations like DSMZ-81, include various vitamins, which are generally omitted from the basic minimal media optimized for electroautotrophic C. necator growth by [Sydow et al](https://doi.org/10.1002/elsc.201600252):
• Vitamins: The modified DSMZ81 mineral medium used by [Nyyssölä et al. (2021)](https://doi.org/10.1021/acsfoodscitech.0c00129) and the medium used by [Yang et al. (2021)](https://doi.org/10.1016/j.jclepro.2021.125921) explicitly included a comprehensive vitamin solution. This typically included riboflavin, thiamine-HCl, nicotinic acid, pyridoxine-HCl, Ca-pantothenate, biotin, and vitamin B12. 

[Nyyssölä et al.](https://doi.org/10.1021/acsfoodscitech.0c00129) noted that both strains they tested could also grow in the absence of these vitamins.

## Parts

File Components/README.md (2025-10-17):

# electroPioreactor Components

## Unique Components

- 1x [Vial Cap](Vial%20Cap)

## Pioreactor

1. 1x [Pioreactor 20ml](https://pioreactor.com/products/pioreactor-20ml?variant=46984254586936)
1. 1x [Peristaltic Pumps](https://pioreactor.com/products/peristaltic-pump)
1. 1x [Dovetail Platform for Pioreactor and Pumps](https://pioreactor.com/collections/accessories-and-parts/products/pioreactor-and-pump-dovetail-platform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)

## Media vessel options

### Centrifuge Tubes

1. 2x [Autoclavable](https://www.starlabgroup.com/GB-en/product/50-ml-centrifuge-tubes-pf-sl-9455674.html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) or [Not](https://amzn.eu/d/9wjwtFf)
1. 2x [Dovetail centrifuge tube holders](https://github.com/oplz/DormantBioLabResources/blob/main/Prints/dovetailed_rack/50ml_tube_rack.stl)

OR

### GL45 Bottles

1. 2x [Caps](https://pioreactor.com/collections/accessories-and-parts/products/gl45-cap-with-luer-lock-connectors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)
1. 2x [250 ml Bottles](https://www.theconsumablescompany.com/250ml-reagent-bottle-borosilicate/)
1. 2x [Dovetail Duran holders 0.25L](https://www.printables.com/model/1058356-duran-bottle-holding-platform-for-pioreactor-platf/files)

## Electrolysis

1. Either  
   - 1x Platinum plated titanium anode (for MEP0.02Pt – 6mm diameter, 60mm total length, 35mm platinised length), or  
   - 1x Graphite anode (for MEP0.02C – 6mm diameter, 60mm total length)  
1. 1x Crocodile clip
1. Either
   - Bolt option
     1. 1x Stainless Steel 60mm M4 bolt
     2. 1x Stainless Steel M4 Locking Nut
     3. 1x Ring Crimp Terminal, or
    - 1x Stainless Steel anode (6mm diameter, 60mm total length)
1. 4x Female Dupont Cables: [Amazon.co.uk](https://amzn.eu/d/fKdnqrx) (also needed for CO<sub>2</sub> sparging)

### CO<sub>2</sub> sparging

1. 1x Sodastream cylinder: [Amazon.co.uk](https://amzn.eu/d/1dZqKsi) (classic blue NOT quick connect pink)
1. 1x [Sodastream holder for Pioreactor](https://www.printables.com/model/855700-sodastream-holder-for-pioreactor)
1. 1x W21.8-14 to TR21-4 adaptor: [Amazon.co.uk](https://amzn.eu/d/1eZLJ7n) [^1]
1. 1x CO<sub>2</sub> Regulator and Solenoid: [Amazon.co.uk](https://amzn.eu/d/gSnMfxg)
1. ~ 20cm 4mm PU tubing: [Amazon.co.uk](https://amzn.eu/d/h9DJO5H)
1. 2x Check valves: [Amazon.co.uk](https://amzn.eu/d/giKnew4)
1. 1x 3/16" barb male Luer lock: [Amazon.co.uk](https://amzn.eu/d/83w3N6F)
1. 1/16" barb Luer Locks - 2x Male: [Amazon.co.uk](https://amzn.eu/d/5yACgUp) & 2x Female: [Amazon.co.uk](https://amzn.eu/d/deEBv9w)
1. ~ 20cm 1/16" ID Silicone tubing: [Amazon.co.uk](https://amzn.eu/d/bOQ02Ow)
1. 1x 2.1mm x 5.5mm Male Barrel Plug: [Amazon.co.uk](https://amzn.eu/d/d5QFCxD) - to connect Raspberry Pi to solenoid with:

### Reagents

* See this post: https://forum.amybo.org/d/22-hob-culture-medium-ingredients/7

## Optional extras

1. Spare 20ml glass vials: [Amazon.co.uk](https://amzn.eu/d/fbFWJ66)

### Recommended Budget Labware

1. 1x [1-5ml Pipettor](https://amzn.eu/d/9jKUSIx) & [tips](https://amzn.eu/d/cSiLNzj)
1. 1x Nitrile Gloves: [Amazon.co.uk](https://amzn.eu/d/iIR5cf6)
1. 1x Spatula: [Amazon.co.uk](https://amzn.eu/d/houYNco)
1. 1x Weighing Boat: [Amazon.co.uk](https://amzn.eu/d/iaNhVpD)
1. Jewellers Scales
1. 1x 1L volumetric flask: [Labpals](https://www.labpals.co.uk/product-page/1000ml-volumetric-flask-with-polyethylene-stopper-borosilicate-glass-class-a)
1. 1x 1L Reagent Bottle: [Labpals](https://www.labpals.co.uk/product-page/clear-borosilicate-glass-reagent-bottle-with-screw-cap-1000-ml-with-graduations)
1. 1x 1L Amber Reagent Bottle: [Labpals](https://www.labpals.co.uk/product-page/amber-borosilicate-glass-reagent-bottle-with-screw-cap-1000-ml-with-graduations)
1. 1x 1L Wash Bottle: [Labpals](https://www.labpals.co.uk/product-page/1000-ml-performance-plastic-wash-bottle-distilled-water-labeled-4-color)

### Recommended Tools for Assembly
1. 1x Crimping Pliers: [Amazon.co.uk](https://amzn.eu/d/5pGr9b4)
1. 1x 150mm Pliers Wrench: [Amazon.co.uk](https://amzn.eu/d/3nkLCuu)
1. 1x Needle-Nose Pliers: [Amazon.co.uk](https://amzn.eu/d/74U0lou)
1. 1x PH0 Screwdriver: [Amazon.co.uk](https://amzn.eu/d/houYNco)

[^1]: Could be improved, I got this as it is also a 90° bend, but mine is uncomfortably stiff to adjust

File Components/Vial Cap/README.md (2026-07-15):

# Vial Cap + electrode holder

`Vial Cap.scad` is a parametric vial cap, septum and electrode top-stop in one OpenSCAD file. It supersedes the original O-ring cap and the separate ElectrodeTopStop, and can still reproduce the old O-ring cap via `seal = "oring"`.

`Vial Cap.stl` is a render of the default configuration (the one-piece holder).

## Requires

BOSL2 for the GPI 24-400 internal thread (same as the original cap): https://github.com/BelfrySCAD/BOSL2

For fast rendering: use the nightly OpenSCAD and set Preferences -> Advanced -> Backend to "Manifold (new/fast)".

## What it does

- Seals with a full-width silicone septum instead of O-rings. One sheet seals the vial mouth, around each electrode, every port, and self-heals sampling-needle tracks. Set `seal = "oring"` to bring back the original cap O-ring groove and the electrode O-ring grooves instead.
- Holds the electrodes with no play: a long journal bore plus an M3 wire clamp, referenced back to the cap.
- Parametric insertion depth: enter the electrode length and the protrusion you want into the vial, and the column height follows.
- Pioreactor-1.5 poka-yoke flange (rotatable via `flange_angle`), grip ribs (optional), GPI 24-400 thread.
- Prints support-free, either as a separate cap + top stop (`pieces = 2`) or as one piece (`pieces = 1`, top-stop down on the bed).
- Optional big septum openings (with an adjustable wall tilt) and optional per-port needle guides at the top-stop face.

## Options

All options are at the top of the file and commented inline. The main ones:

- Display / build: `view`, `part`, `pieces`
- Cap: `seal` (septum / oring), `port_style`, `ribs`, `flange_angle`
- Counts and sizes (as the original cap): `electrodes`, `el_d`, `n_ports`, `port_d`
- Septum access: `openings`, `opening_tilt`
- Needle guides: `guides`, `guide_h`, `guidexmin_wall`
- Print settings: `layer_h`, `min_wall`

In `oring` mode the seal sizes are `cap_o_ring_cs`, `electrode_o_ring_cs` and `electrode_cutout`; the closed-top thickness grows automatically so there is enough material to seat the cap O-ring (the electrodes used 5 mm ID / 9 mm OD / 2 mm CS O-rings).

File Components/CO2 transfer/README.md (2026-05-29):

# CO2 Transfer
## Process flow
1. SodaStream cylinder (procured locally by end-user)
1. Thread adapter (if necessary)
1. [Regulator](Regulators.md)
1. [Needle Valve](NeedleValves.md)
1. [Solenoid](VentingSolenoids.md) (if intermittent sparging)
1. Check Valve
1. Flow meter
1. Tubing
1. Filter
1. Sparge tubing

## Premium Options
1. SodaStream cylinder (procured locally by end-user)
1. [Premium ODL Sodastream Regulator](https://brewkegtap.co.uk/products/premium-sodastream-regulator-made-in-italy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) £65
1. [G1/8" Stainless steel Needle Valve PTFE 300 bar - NLS](https://tameson.co.uk/products/nls-018-g1-8inch-stainless-steel-needle-valve-ptfe-300-bar) £26.38
1. [Bürkert Type 7017 20076521](https://www.burkert.co.uk/en/products/solenoid-valves/general-purpose-3-2-solenoids/20076521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) £99.40
1. [Omega Variable Area Flowmeter](https://www.omega.co.uk/pptst/FLD.html) £142.12
1. [Hydraulic Check Valve Cutting Ring 8L (M14x1.5) & G1/4'' Male Stainless Steel 0.2-250bar (3-3625)psi Tube-Thread ISO 8434-1](https://tameson.co.uk/products/f2czy-hydraulic-check-valve-cutting-ring-8l-m14x1p5-g1-4inch-male-stainless-steel-0p2-250bar-3-3625-psi-tube-thread-iso-8434-1) £51.24
1. Tubing
1. Filter
1. Sparge tubing

## Budget Options
1. SodaStream cylinder (procured locally by end-user)
1. [2 in 1 Mini CO2 Gas Regulator Soda Pressure Gauge](https://www.manomano.co.uk/p/co2-pressure-regulator-2-in-1-mini-co2-gas-regulator-soda-pressure-gauge-with-38in-to-tr214-adapter-for-sodastream-88562182) £25.54
1. [HP Control R23](https://hpcontrol.uk/elektrozawor-r23-1-8-cala-2-lub-3-drogowy-laczony-w-grupy.html) £11.29
1. [Inline CO2 Needle Valve For Planted Aquarium Systems](https://www.co2supermarket.co.uk/product/co2-needle-valve-inline-93)
1. [CO2 Bubble Counter & Integrated Check Valve For Regulators](https://www.co2supermarket.co.uk/product/co2-bubble-counter-for-regulators-check-valve-27) £9.99
1. Tubing
1. Filter
1. Sparge tubing

## Trialled Option (continuous sparging)
1. SodaStream cylinder (procured locally by end-user)
1. [Premium ODL Sodastream Regulator](https://brewkegtap.co.uk/products/premium-sodastream-regulator-made-in-italy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) £65
1. [1/4" BSPT MALE x 1/8" BSPP FEMALE HEX REDUCING BUSH-RB-150-04-02](https://customfittings.com/products/bspt-male-bsp-female-hex-reducing-bush-rb-150-04-02) £3.76
1. [CO2 Needle Valve For Regulator Or Solenoid](https://www.co2supermarket.co.uk/product/precision-co2-needle-valve-for-regulator-solenoid-564) £15.99
1. [CO2 Bubble Counter & Integrated Check Valve For Regulators](https://www.co2supermarket.co.uk/product/co2-bubble-counter-for-regulators-check-valve-27) £9.99
1. Tubing
1. Filter
1. Sparge tubing

It was however found that intermittent sparging was preferred, and that the CO2 leakage with the [Premium ODL Sodastream Regulator](https://brewkegtap.co.uk/products/premium-sodastream-regulator-made-in-italy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) on SodaStream cylinder changeover was unacceptable so we moved to:

## Current Solution (as of 29 May 2026)
1. SodaStream cylinder (procured locally by end-user)
1. [Kegland Deluxe Sodastream Cylinder Adapter (with pin adjustment) (EU Thread) W21.8 male to TR21-4 female](https://kegland.eu/products/deluxe-sodastream-cylinder-adapter-with-pin-adjustment-eu-thread-w21-8-male-to-tr21-4-female) ~[£6 via AliExpress](https://www.aliexpress.com/item/1005005413860080.html)
1. [Premium ODL Sodastream Regulator](https://brewkegtap.co.uk/products/premium-regulator-made-in-italy) £60
1. [1/4" male to 1/8" male reducing hexagon nipple](https://www.bearingsrus.co.uk/rhn0402-1-4-bsp-x-1-8-bsp-male-male-reducing-hexagon-nipple) £1.24 (or if you want to save on shipping you could order a [reducer](https://hpcontrol.uk/redukcja-nierdzewna-gz-1-4-gw-1-8.html) and [nipple](https://hpcontrol.uk/nypel-nierdzewny-gz-1-8-gz-1-8.html) with your solenoid, but this increases leak risk) 
1. [HP Control R23](https://hpcontrol.uk/elektrozawor-r23-1-8-cala-2-lub-3-drogowy-laczony-w-grupy.html) - 12V DC £11.29
1. [1/8" male blanking plug](https://hpcontrol.uk/korek-1-8-cala-oring.html)
1. [CO2 Needle Valve For Regulator Or Solenoid](https://www.co2supermarket.co.uk/product/precision-co2-needle-valve-for-regulator-solenoid-564) £15.99
1. Tubing
1. 3x [0.2μm 25mm dia hydrophobic filter](https://www.theconsumablescompany.com/exapure-syringe-filter-25mm-0-2%c2%b5m-ptfe-membrane/) £1.83 (one on inlet, two on outlet to reduce overpressure risk)
1. Sparge tubing

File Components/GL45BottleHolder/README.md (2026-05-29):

# GL45 Bottle Holder

Pioreactor dovetail platform holder for a GL45 Duran bottle, in 250 ml, 500 ml and 1000 ml sizes.

## What to print

Pick your bottle size:

- [`GL45_holder_250ml.stl`](GL45_holder_250ml.stl)
- [`GL45_holder_500ml.stl`](GL45_holder_500ml.stl)
- [`GL45_holder_1000ml.stl`](GL45_holder_1000ml.stl)

## What this fixes

The upstream Duran holders (e.g. [Printables 1058356](https://www.printables.com/model/1058356-duran-bottle-holding-platform-for-pioreactor-platf/files)) have lettering cut into the four corners. The recessed letter shapes trap residue and resist cleaning. This component renders the same geometry but with the corner lettering filled by smooth caps, leaving the rest untouched.

## Re-rendering / other sizes

`GL45_holder.scad` is the source. Open it in OpenSCAD, set `bottle_ml` to `250`, `500` or `1000`, then render and export. The three STLs above are produced this way, so they stay in sync with the SCAD.

## Files

- [`GL45_holder.scad`](GL45_holder.scad) – source recipe; set `bottle_ml` to choose the size
- `GL45_holder_250ml.stl` / `GL45_holder_500ml.stl` / `GL45_holder_1000ml.stl` – **ready to print**
- `source/` – the upstream Duran holders, kept in-repo so the SCAD renders offline. Not for printing.

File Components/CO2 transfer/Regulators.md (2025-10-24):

# Regulators

## Inlet connector
[SodaStream adapters](https://www.co2supermarket.co.uk/category/sodastream-cylinder-adapters-2) tend to cost >£10, so this cost should be taken into consideration when determining whether to use a SodaStream native regulator, or one that comes bundled with a SodaStream adapter.  SodaStream native would be preferable, to minimise the number of connections, reducing bulk, complexity and leak risk.

## Outlet connector
The outlet connector should ideally match the downstream units' connector types for configuration flexibility and minimising the number of unique parts (assuming all parts are female-female and require male-male connectors).  
In order to avoid the need for complex interconnections, if a bubble counter or variable area flow meter (rotameter) is required for flow rate monitoring the outlet will need to be horizontal.

### Other selection criteria
1. **CO₂ compatibility:** All wetted materials must tolerate dry (and ideally also humid) CO₂ exposure without swelling or corrosion.
1. **Wetted materials:** Prefer food-grade, non-cytotoxic materials (e.g. FKM, EPDM, PTFE, PPS, or stainless steel).
1. **Sterilisability:** Ideally capable of cleaning or sterilisation (EtOH, peracetic acid, or autoclave resistance desirable).
1. **Certifications:** CE/UKCA and RoHS compliance required; FDA/EU 1935/2004 desirable.
1. **Form factor:** Compact size for integration with the electroPioreactor system; standard threads to allow short, direct connections to other equipment.

## Preferred Option?
[Premium ODL Sodastream Regulator](https://brewkegtap.co.uk/products/premium-sodastream-regulator-made-in-italy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) £65
SodaStream-native (TR21-4) inlet with 3/8″ John Guest push-fit outlet; includes built-in relief valve and 0–80 psi gauge. Compact, CO₂-compatible and adjustable.
No CE/UKCA, RoHS, or food-grade certification listed; sterilisation capability unspecified.  Only 6 currently available.
### Outstanding questions
1. Are you getting more in? - they have plenty
1. What is the connector thread type to the John Guest outlet? - 1/4" BSPP
1. Does it have UKCA, RoHS, food-grade and/or any other certification? - doesn't know, nothing on box, but they are intended for food.
1. How can it be sterilised? - don't know, thinks wouldn't want to put things through
1. Does it have a check valve at the outlet? - would need to buy sepatrately, they sell john guest.
1. Do you sell compatible needle valves, bubble meters or rotatmeters? - send Alan an email at orders@brewkegtap.co.uk

## Affordable dual-guage tool-less option
[Kegland Mk5 Beverage CO2 Regulator (with included SodaStream adapter)](https://brewkegtap.co.uk/products/new-sodastream-kegland-mk5-beverage-co2-regulator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) £52.00
Nickel-plated brass body with steel components and polymer seals, CE-marked, includes SodaStream adapter and push-fit outlets; compact and CO₂ compatible.
No CE or food-grade certification listed and outlet at irregular angle.
### Outstanding questions
1. What is the connector thread type to and from the globe valve?
2. Can the gauges be rotated to a vertical orientation?
3. Will angles work to attach downstream bubble counter?

## Compact gaugeless option
[DreamsDesign SR-Micro CO₂ Pressure Regulator](https://www.hommix.co.uk/products/dreamsdesign-sr-micro-co2-pressure-regulator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) £39.99
Compact anodised-aluminium and stainless-steel regulator. TR21-4 SodaStream thread, 1/8″ BSPP outlet with ¼″ push-fit adapter.
Adjustable 1.5–6 bar, 130 bar max inlet, 1/8" BSPP outlet, assumed horizontal.
No CE or food-grade certification listed.  No fine pressure readout.

## Compact option with gauge
[Kegland Mini Co2 Regulator Threaded Co2 Soda Stream Type](https://brew-day.co.uk/product/kegland-mini-co2-regulator-threaded-co2-soda-stream-type/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,Co2%20Soda%20Stream%20Type) £39.95
SodaStream‑native inlet and barbed male outlet (no adapter needed), compact anodised‑aluminium body with push‑on gas outlet, simple portable design
brew-day.co.uk
Lacks dual gauges and high‑accuracy controls; material/compliance, pressure range, CE/UKCA and sterilisation capability are unspecified

## Budget option
[2 in 1 Mini CO2 Gas Regulator Soda Pressure Gauge](https://www.manomano.co.uk/p/co2-pressure-regulator-2-in-1-mini-co2-gas-regulator-soda-pressure-gauge-with-38in-to-tr214-adapter-for-sodastream-88562182) £25.54
Copper-bodied mini CO₂ regulator with brass fittings, polymer seals, and TR21.4 adapter for direct SodaStream connection; includes 3/8" horizontal outlet and 30 psi gauge. Not rated food-grade or CE-marked. Single, low accuracy gauge.

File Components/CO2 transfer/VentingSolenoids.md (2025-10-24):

# Venting Solenoid Valves
## Selection Criteria
### Venting
Non-venting solenoid valves result in backflow as, when they shut, they trap a volume of CO2 between the solenoid and the broth (largely water).  As [determined by Eli Silver at Brown](../../Past%20research/Brown%20-%20Harris%20Lab/1.%20CO2%20backflow%20diagnosis%20-%20Eli%20Silver.md) this CO2 completely dissolves in the water drawing the water back up to the valve.  Given that the Aseptic electroPioreactor requires filters between the solenoid valve and the broth, this is unacceptable.  

As [demonstrated by Eli Silver](../../Past%20research/Brown%20-%20Harris%20Lab/2.%20Backflow%20testing%20with%20revised%20components%20-%20Eli%20Silver.md) this can be resolved by employing a 3/2 venting solenoid which connects the reactor to the CO2 supply when closed and vents the reactor to atmosphere when open.

### Other selection criteria
1. **Voltage:** Pioreactor peristaltic pumps are most [accurate at 12 V DC](https://pioreactor.com/products/peristaltic-pump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), if a second power supply is being used for this purpose, it would likely be preferable to not require a third for the solenoid valve.  If 12 V was not being supplied for the peristaltic pumps, 5 V DC solenoids could potentially run from the single Raspberry Pi power supply, however 5 V DC venting solenoids tend to be rare, sub-miniature and use push-fit or non-standard connectors.
1. **Direct-acting operation:** Must function from 0 bar differential pressure (no pilot assist).
1. **CO₂ compatibility:** All wetted materials must tolerate dry (and ideally also humid) CO₂ exposure without swelling or corrosion.
1. **Wetted materials:** Prefer food-grade, non-cytotoxic materials (e.g. FKM, EPDM, PTFE, PPS, or stainless steel).
1. **Sterilisability:** Ideally capable of cleaning or sterilisation (EtOH, peracetic acid, or autoclave resistance desirable).
1. **Operation:** Manual actuation, bistable or latching preferred so solenoid valve does not need to be continuously actuated or removed for continuous CO₂ sparging.
1. **Certifications:** CE/UKCA and RoHS compliance required; FDA/EU 1935/2004 desirable.
1. **Form factor:** Compact size for integration with the electroPioreactor system; standard threads to allow short, direct connections to other equipment.

## Why not use the valve trialled at Brown?
The [solenoid valve trialled at Brown](https://a.co/d/0sMpHv1) is harder to procure in the UK. Both it, and a [1/8" BSP version](https://amzn.eu/d/7Ma3tM2) sold via amazon.co.uk are  pilot operated, requiring minimum 1.7 bar.  They are also not intended for aseptic use.

## Preferred options
### FDA / EC 1935/2004 compliant
[Bürkert Type 7017 20076521](https://www.burkert.co.uk/en/products/solenoid-valves/general-purpose-3-2-solenoids/20076521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) £99.40
3/2 universal, 12 V DC, direct-acting, PPS body, FKM seals, –1 to 1.5 bar, media-separated, chemically sterilisable, implicitly CO₂ compatible, FDA / EC 1935 / 2004 / NSF 169 compliant, 6 mm push-fit ports.
Not autoclavable above 80 °C, latching, or with standard threaded connectors.

### Latching with standard ports
[Bürkert Type 6014 343200](https://www.burkert.co.uk/en/products/process-and-control-valves/shut-off-valves-on-off/pneumatic-control/343200) £167
3/2 NC, 12 V DC, direct-acting, stainless-steel body, FKM seals, 0–16 bar, chemically sterilisable, implicitly CO₂ compatible, latching (pulse version) with G 1/8" BSPP ports.
Not autoclavable above 120 °C, media-separated, or food-certified.

### HP Control R23 (Selected Low-Cost Direct-Acting Valve)
[HP Control R23](https://hpcontrol.uk/elektrozawor-r23-1-8-cala-2-lub-3-drogowy-laczony-w-grupy.html) £11.29
3/2 or 2/2 universal, 12 V DC, direct-acting, aluminium body, NBR seal, 0–8 bar (16 bar max), filtered air medium, manual override, IP65 coil with LED DIN plug, G 1/8″ BSPP ports plus M5 exhaust connector, group-mountable (modular valve island type).
Not media-separated, chemically sterilisable, or food-certified.

### Low cost valve Assessment Summary
A comparative assessment of a number valves considered (including the R23, TAILONZ 3V210-08, and other sub-£30 models) can be found in [Venting Solenoids under £30.md](Venting%20Solenoids%20under%20£30.md).

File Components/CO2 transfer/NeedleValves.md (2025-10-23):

# Needle Valves
## Requirement
Most CO2 regulators have insufficient control resolution to be able to precisely control the low gas flow rates required for continuous CO₂ sparging.  Needle valves offer the most accurate flow control.

### Selection criteria
1. **CO₂ compatibility:** All wetted materials must tolerate dry (and ideally also humid) CO₂ exposure without swelling or corrosion.
2. **Wetted materials:** Prefer food-grade, non-cytotoxic materials (e.g. FKM, EPDM, PTFE, PPS, or stainless steel).
3. **Sterilisability:** Ideally capable of cleaning or sterilisation (EtOH, peracetic acid, or autoclave resistance desirable).
4. **Certifications:** CE/UKCA and RoHS compliance required; FDA/EU 1935/2004 desirable.
5. **Form factor:** Compact size for integration with the electroPioreactor system; standard threads to allow short, direct connections to other equipment.

## Stainless
[G1/8" Stainless steel Needle Valve PTFE 300 bar - NLS](https://tameson.co.uk/products/nls-018-g1-8inch-stainless-steel-needle-valve-ptfe-300-bar) £26.38
Stainless-steel 316 body, PTFE seals, 0–300 bar, –20 to 200 °C, implicitly CO₂ compatible, G 1/8″ BSPP ports, providing precise flow control and full shut-off capability.
Not media-separated or food-certified.

## Budget
[G1/8" Nickel Plated Brass Needle Valve NBR 18 bar - NLBN](https://tameson.co.uk/products/nlbn-018-g1-8inch-nickel-plated-brass-needle-valve-nbr-18-bar) £7.98
Nickel-plated brass body, NBR seals, 0–18 bar, –10 to 80 °C, implicitly less CO₂ compatible, G 1/8″ BSPP ports, providing precise flow control and full shut-off capability.
Not media-separated or food-certified.

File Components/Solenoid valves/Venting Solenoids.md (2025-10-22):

# Venting Solenoid Valves
## Selection Criteria
### Venting
Non-venting solenoid valves result in backflow as, when they shut, they trap a volume of CO2 between the solenoid and the broth (largely water).  As determined by [Eli Silver at Brown](../../Past%20research/Brown%20-%20Harris%20Lab/1.%20CO2%20backflow%20diagnosis%20-%20Eli%20Silver.md) this CO2 completely dissolves in the water drawing the water back up to the valve.  Given that the Aseptic electroPioreactor requires filters between the solenoid valve and the broth, this is unacceptable.

### Other selection criteria
- **Direct-acting operation:** Must function from 0 bar differential pressure (no pilot assist).
- **Voltage:** 12 V DC or below preferred for compatibility with standard control systems.
- **Venting function:** Must exhaust trapped CO₂ to atmosphere when de-energised.
- **CO₂ compatibility:** All wetted materials must tolerate dry and humid CO₂ exposure without swelling or corrosion.
- **Wetted materials:** Prefer food-grade, non-cytotoxic materials (e.g. FKM, EPDM, PTFE, PPS, or stainless steel).
- **Sterilisability:** Ideally capable of cleaning or sterilisation (EtOH, peracetic acid, or autoclave resistance desirable).
- **Manual override:** Manual actuation preferred for testing and safety.
- **Certifications:** CE/UKCA and RoHS compliance required; FDA/EU 1935/2004 desirable.
- **Pressure and temperature range:** Suitable for 0–8 bar and 0–70 °C operating conditions.
- **Form factor:** Compact size for integration near the reactor vessel; standard BSPP or compatible threads.

## Why Not use the valve trialled at Brown?
The [solenoid valve trialled at Brown](https://a.co/d/0sMpHv1) is harder to procure in the UK, both it, and a [1/8" BSP version](https://amzn.eu/d/7Ma3tM2) sold via amazon.co.uk are not intended for Aseptic use, they are also pilot operated, requiring minimum 1.7 bar.

## Valve selection
### Bürkert 6014 (Optimum / Food-Grade Option)
The [Bürkert 6014](https://tameson.co.uk/products/solenoid-valve-3-2-way-g1-8-bistable-brass-fkm-0-16bar-232psi-12vdc-latching-6014-209280) is available in G 1/8″ BSPP configuration, with versions featuring latching coils, FKM or EPDM seals, and materials compliant with FDA, EU 1935/2004, and USP Class VI standards.  

### HP Control R23 (Selected Low-Cost Direct-Acting Valve)
The [HP Control R23](https://hpcontrol.uk/elektrozawor-r23-1-8-cala-2-lub-3-drogowy-laczony-w-grupy.html) is a low-cost venting valve, selected for its direct-acting design and ability to operate from 0 bar.  
It has 1/8″ BSPP in/out ports (hence interchangeable with the similar Bürkert 6014's) it has an M5 vent, a 12 V DC coil, and includes a manual override.  
Although not food-grade, it is CE- and RoHS-certified and suitable for dry CO₂ use post-regulator.  

### Low cost valve Assessment Summary
A full comparative assessment of all valves considered (including the R23, TAILONZ 3V210-08, and other sub-£30 models) can be found in [Venting Solenoids under £30.md](Venting%20Solenoids%20under%20£30.md).  
That concludes that the R23 provides the best compromise for low-pressure CO₂ venting.

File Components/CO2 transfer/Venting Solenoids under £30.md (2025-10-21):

# 3/2‑Way Venting Solenoid Valves under £30 (UK & EU)

## ChatGPT5 Agent Overview

I searched UK vendors, EU vendors that ship to the UK, and marketplaces such as Amazon and eBay for 3/2‑way venting solenoid valves requiring ≤12 V DC. Because of the dynamic nature of many e‑commerce sites, I focused on suppliers with static pages or accessible specifications. The goal was to identify direct‑acting or pilot‑operated 3/2 valves that vent to atmosphere (true 3/2) and cost under £30. Duplicate models were consolidated and the cheapest seller is listed. Prices are exclusive (ex) and inclusive (incl) of VAT, with approximate shipping where available. Exchange rates of €1 = £0.87 were used for EU prices.

## Candidate valves (sorted by price ex VAT)

| Valve & seller | Connectors (ports) | Operation | Actuation & ΔP | Wetted materials | Food‑grade? | Regulations | CO₂ compat.? | Voltage & coil / connector | Path (3/2 vent?) | Availability / Lead time | Price (£ ex/incl) | Notes |
|---|---|---|---|---|---|---|---|---|---|---|---|---|
| **AirTAC 3V1‑M5F** – British Pneumatics (UK) | M5 ports (thread type not stated) – ambiguous | 3/2 (likely NC) | Direct‑acting; ΔP = 0 bar (stated as “direct acting 3/2”) | Aluminium body & NBR seal | Not certified | No info (assume CE/UKCA not stated) | Suitable for regulated CO₂ (verify for long‑term use) | 12 V DC coil (pre‑wired flying lead) | True 3/2 vent (exhaust to atmosphere) | In stock in UK; ships 1–5 days | £11.50 ex / £13.80 incl | Cheapest option; widely used model (3V1 series). Alt vendors on eBay & AliExpress. |
| **TAILONZ PNEUMATIC 3V110‑06 (UK Amazon)** | 1/8″ BSP ports (all three) | NO (stated “open when de‑energised”) | Pilot‑operated; ΔP ≥ 0.17 MPa (1.7 bar min) | Aluminium body; NBR seal | Not certified | CE marked (manufacturer declaration) | Suitable for dry CO₂ use (post‑regulator) | 12 V DC coil (pre‑wired) | 3/2 venting configuration (listing confirmed) | In stock on Amazon UK; ships next day | £11.99 ex / £14.39 incl | Low‑cost pneumatic valve; requires pressure to operate but may function for regulated CO₂ applications. |
| **TAILONZ PNEUMATIC 3V210‑08 (US Amazon)** | 1/4″ NPT ports (all three) | NO (stated “open when de‑energised”) | Pilot‑operated; ΔP ≥ 25 psi (1.7 bar min) | Aluminium body; NBR seal | Not certified | CE marked (manufacturer declaration) | Suitable for dry CO₂ use (post‑regulator) | 12 V DC coil (pre‑wired) | True 3/2 venting (verified by Harris Lab, Brown University) | Ships from US to UK (~£7 import fee) | $15.99 ≈ £14.00 + shipping | Tested and proven to vent properly under CO₂ control conditions; thread adapters needed for BSP systems. |
| **HP Control 3V210‑08 (HPControl EU)** | G ¼″ BSPP female ports (all three) | NC (3/2) | Pilot‑operated; ΔP ≥ 1.5 bar (min pressure) | Aluminium body; NBR seal | Not certified | CE marked; RoHS compliant | Suitable for dry regulated CO₂ above 1.5 bar only (not for atmospheric venting) | 12 V DC coil with DIN plug and manual override | 3/2 function requires pilot pressure – not true vent from 0 bar | In stock; ships from Poland within 24 h | €9.75 ex / €11.96 incl ≈ £10.40 incl | High‑flow 3/2 valve for pneumatics; unsuitable for low‑pressure CO₂ venting applications but useful for > 1.5 bar air control. |
| **HP Control R23 (HPControl EU)** | 1/8″ BSPP in/out + M5 vent | NC (selectable 2/2 or 3/2) | Direct‑acting; ΔP = 0 bar | Aluminium body; NBR diaphragm | Not certified | CE marked; RoHS compliant | Suitable for dry regulated CO₂ (post‑regulator) | 12 V DC coil with LED DIN plug | True 3/2 vent to atmosphere | In stock; ships from Poland in 2–5 days | €13.25 ex / €16.25 incl ≈ £14.15 incl | Direct‑acting valve works from 0 bar; manual override; excellent low‑cost option. |
| **Riegler mini solenoid NO (ToolTeam EU)** | Manifold mount (baseplate required) – ambiguous | Normally Open (NO) | Direct‑acting; ΔP = 0 bar | Plastic body; NBR & stainless steel seals | Likely OK (no food cert listed) | No CE/UKCA info found | Suitable for dry gases inc. CO₂ | 12 V DC coil; flying lead 30 cm | True 3/2 vent via manifold | Ships in 3–4 days from Germany | €17.77 ex / £15.47 ex ≈ £18.50 incl | Compact valve; requires manifold; price varies by vendor. |
| **Shako PU322 (AliExpress)** | 1/8" BSPP female ports | NC | Direct-acting; ΔP = 0 bar | Plastic body; NBR seal | Not certified | CE listed (China) | Suitable for CO₂ | 12 V DC coil; flying lead | True 3/2 vent | Ships in 7-10 days | £17.50 ex / £21.00 incl | Low cost; Chinese origin; check quality. |
| **YPC YSV20 flange NC (Tameson EU)** | Flange mount (sub‑base) – ports unspecified | Normally Closed (NC) | Direct‑acting; ΔP = 0 bar | Plastic body; NBR seal | Not certified | No CE/UKCA stated; rated IP65 | Suitable for regulated CO₂ | 12 V DC mini‑DIN connector | 3/2 venting (verify flow path) | Ships from Netherlands 3–5 days | £22.09 ex / £26.51 incl | Good value direct‑acting flange valve; compact size. |
| **Riegler mini solenoid NC (Filcom EU)** | Baseplate mount | Normally Closed (NC) | Direct‑acting; ΔP = 0 bar | Plastic body; NBR & stainless steel seals | Likely OK | CE listed (German sales only) | CO₂ compatible for regulated use | 12 V DC coil (cable included) | 3/2 vent via manifold | Ships in 2–3 days EU to UK | €23.42 ex / ≈ £20.38 ex ≈ £24.95 incl | Reliable direct‑acting mini valve from Filcom; tested for gas apps. |
| **Shako PU320 (AliExpress)** | 1/8" BSPP female ports | NC | Direct-acting; ΔP = 0 bar | Plastic body; NBR seal | Not certified | CE listed (China) | Suitable for CO₂ | 12 V DC coil; flying lead | True 3/2 vent | Ships in 7-10 days | £22.00 ex / £26.40 incl | Similar to PU322; slightly higher price. |
| **Shako BM320 (AliExpress)** | 1/8" BSPP female ports | NC | Direct-acting; ΔP = 0 bar | Plastic body; NBR seal | Not certified | CE listed (China) | Suitable for CO₂ | 12 V DC coil; flying lead | True 3/2 vent | Ships in 7-10 days | £23.00 ex / £27.60 incl | Slightly larger valve; good flow. |
| **Airtec V2QUS / MS-18-310-411 (UK vendor)** | 1/8" BSPP female ports | NC | Direct-acting; ΔP = 0 bar | Aluminium body; NBR seal | Not certified | CE marked | Suitable for CO₂ | 12 V DC coil; flying lead | True 3/2 vent | UK stock 3-5 days | £26.00 ex / £31.20 incl | Aluminium body; robust build. |
| **Airtac MS 1/8 G BSPP NC (UK)** | 1/8″ BSPP female ports | NC | Pilot‑operated; ΔP ≥ 0.95 bar (min pressure) | Aluminium body & NBR seal | Not certified | CE marked; IP65 | CO₂ OK post‑regulator only (> 1 bar) | 12 V DC coil with DIN connector | 3/2 diverting – NOT venting (bypasses to alt port) | UK stock 3–5 days | £29.97 ex / £35.96 incl | Exceeds budget incl VAT but included for comparison. Needs > 1 bar ΔP. |

## Notes

- Prices verified October 2025.  
- Shipping times are typical but may vary post‑Brexit.  
- Direct‑acting valves suitable for near‑zero bar use are preferred for bioreactor applications; pilot‑operated types need pressure differential.  
- Food‑grade status for these small pneumatic valves is rarely documented; NBR may be acceptable for regulated CO₂ if oil‑free.

## Recommended Valve

### ✅ Recommended Valve: HP Control R23 (HPControl EU)

After reviewing all candidate valves in the table, the **HP Control R23** is the only model that fully meets the functional and practical requirements for post‑regulator CO₂ venting.

| Evaluation Factor | Verdict | Notes |
|---|---|---|
| **True 3/2 venting** | ✅ Yes | Confirmed exhaust to atmosphere via M5 vent. |
| **Operation from 0 bar** | ✅ Yes | Direct‑acting; ΔP = 0 bar. |
| **Voltage range** | ✅ 12 V DC coil with LED DIN plug | Matches system spec. |
| **CO₂ compatibility** | ✅ Good | Aluminium + NBR suitable for dry post‑regulator gas. |
| **Food‑grade** | ⚠️ No certification | Acceptable for non‑contact gas use. |
| **Regulatory compliance** | ✅ CE + RoHS | Verified documentation. |
| **Availability** | ✅ In stock | Ships in 2–5 days from Poland. |
| **Price** | 💰 €13.25 ex / €16.25 incl ≈ £14.15 incl | Well under budget. |
| **Suitability for CO₂ system** | ✅ Excellent | Vents properly even at 0 bar; manual override included. |

**Summary:**  
Among all valves listed, the **HP Control R23** offers the optimal balance of verified CE compliance, 0 bar operation, true 3/2 venting behaviour, and affordability.  
All other models either require pilot pressure, lack confirmed venting, or exceed the £30 limit.

While the **TAILONZ 3V210‑08** (from US Amazon) is the only valve we have tested and confirmed to vent properly under CO₂ conditions (Harris Lab, Brown University), the **HP Control R23** is the recommended choice for low‑pressure venting applications. The R23 is direct‑acting and works from 0 bar, making it more reliable for atmospheric or flooded conditions, even though the TAILONZ unit offers a verified vent function at higher pressures.

### Assessment vs Bioreactor‑Grade Requirements

While the **HP Control R23** is the best of the sub‑£30 class, it and the other valves listed represent **low‑cost compromises** when assessed against the ideal criteria for sterile or cytocompatible CO₂ control.

| Criterion | Ideal Requirement | R23 | Other valves (< £30) |
|---|---|---|---|
| **Non‑cytotoxic / food‑grade** | Certified FDA / EU 1935 / USP VI materials | ❌ No certification (NBR + Al) | ❌ None certified |
| **CO₂ compatibility** | Long‑term stable in dry / humid CO₂ | ⚠️ Dry CO₂ OK only | ⚠️ Variable – NBR seals may swell |
| **Operation after flood** | Functions after liquid backflow | ⚠️ Might stick or short if flooded | ❌ Likely fails if wet |
| **Sterilisable** | Withstands autoclave or EtOH / PAA sanitisation | ⚠️ Limited to ~70 °C cleaning | ❌ Not sterilisable |
| **Latching / bistable** | Magnetic latching reduces heat and EMI | ❌ Continuous coil type | ❌ All continuous coil |
| **Ingress protection** | IP65 or better for washdown / condensation | ✅ IP65 rated coil | ⚠️ Mixed / unstated |
| **Regulatory compliance** | CE + RoHS + Material traceability | ✅ CE / RoHS confirmed | ⚠️ Inconsistent or missing |
| **Maintenance / spares** | Replaceable coil and seals available | ⚠️ Coil replaceable, seals not listed | ⚠️ Unknown |
| **Overall suitability for aseptic bioreactor** | Full food‑safe & sterilisable operation from 0 bar | ⚠️ Functional for non‑sterile test rigs | ❌ Industrial / pneumatic use only |

**Conclusion:**  
All sub‑£30 valves, including the **HP Control R23**, are **functionally suitable for CO₂ control in non‑sterile test rigs or prototyping** but **do not meet bioreactor‑grade standards** for cytocompatibility, sterilisation, or validated food‑contact safety. They remain valuable for low‑budget experimental setups where isolation from culture gas lines is ensured.

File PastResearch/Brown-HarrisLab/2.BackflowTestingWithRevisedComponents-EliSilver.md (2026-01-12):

Following his [CO2 backflow diagnosis](1.CO2backflowDiagnosis-EliSilver.md), Eli Silver conducted some testing with revised components. Everything appears to be working well.  Eli recorded a video showing the system in action so you can see how it all comes together: 
Watch the video on Vimeo (https://vimeo.com/1127824943)

The parts used in this test are:
- [CO2 Regulator](https://www.amazon.com/dp/B0CP98JBCL/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)
- [1/4" NPT F to M needle valve](https://www.amazon.com/dp/B08BNRTHBX/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)
- [Three way solenoid valve](https://www.amazon.com/dp/B0BWDR2L7S/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)
- [push to connect fitting kit](https://www.amazon.com/dp/B0DM1YXHDL/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)
- A 1/4" NPT M to M adapter 
- Some fittings to adapt the push to connect tubing to a hose barb

As shown in the video, using the 1/4" NPT M to M fitting with the needle valve Eli chose allows the entire system to be rigidly mounted to the pressure regulator. Our regulator has a 1/4" NPT F output which seems quite standard. To simplify the system for a next iteration, Eli would buy a needle valve with 1/4" NPT M to M fittings, allowing the needle valve to attach directly to the regulator without the need for the M to M adapter. We also do not need to use the push to connect flexible tubing between the different components, eliminating the need for the tubing kit entirely. The 1/4" NPT F output of the solenoid valve needs to be adapted to the silicone tubing you are already using, probably with a barb or luer-lok fitting.

With these changes, Eli's recommendation for an Aseptic electroPioractor with intermittent sparging would be:
- [CO2 Regulator](https://www.amazon.com/dp/B0CP98JBCL/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) (or something equivalent that will interface directly with the valve on your CO2 tank)
- [1/4" NPT M to M needle valve](https://www.amazon.com/PIC-NV-B-1-4-MXM-Needle-Connection/dp/B00FBQ2GKU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)
- [Three way solenoid valve](https://www.amazon.com/dp/B0BWDR2L7S/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)
- A 1/4" NPT F to barb or luer-lok fitting that matches your tubing

For assembly, some things to look out for are:
- Apply teflon tape to all threaded connections.
- Attach the needle valve to the solenoid valve "P" port. (You can't turn the needle valve if the vent is in place)
- Attach the output barb to the solenoid valve "A" port. 
- Attach the sintered brass vent to the solenoid valve "R" port, or just leave it open up to you.
- Then attach the entire assembly to the regulator by threading the needle valve input to the regulator output.

To adjust the pressure and flow rate, Here is the procedure Eli followed:
- Open the needle valve all the way.
- Leaving the needle valve open, increase the regulator pressure until the solenoid valve opens reliably when current is applied.
- Open the solenoid valve either by applying constant current to the solenoid or pressing and rotating the blue manual valve trigger on the solenoid valve body.
- While the solenoid valve is open, tighten the needle valve until you achieve the desired flow rate. 
- Test that the solenoid valve still opens when current is applied. If it is not opening reliably, increase the regulator pressure further.

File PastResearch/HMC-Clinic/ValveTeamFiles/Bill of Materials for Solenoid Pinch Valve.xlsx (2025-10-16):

Vendor Part Number | Part Name | Part Description | Vendor | Quantity | Total cost | Total Estimated Cost
B09T32M2S6 | DC Solenoid Electromagnet; Model: HS-1564B | Stroke: 20mm ; Force 60N; 4.69 x 1.77 x 1.61 inches; 13.05 ounces; push/pull type; 3Amps | Heschen | 1 | $16.99 | $25.92
 | Solenoid Housing | Solenoid pinch valve housing |  | 1 | $3.46
 | Lever | Solenoid pinch valve lever |  | 1 | $1.00
 | Washers | Washers for stroke length adjustment |  | 7 | $2.00
 | Pinch Valve Support Enacasing | Supports |  | 1 | $2.41
 | Solenoid Hat | Hat for solenoid plunger |  | 1 | $0.06

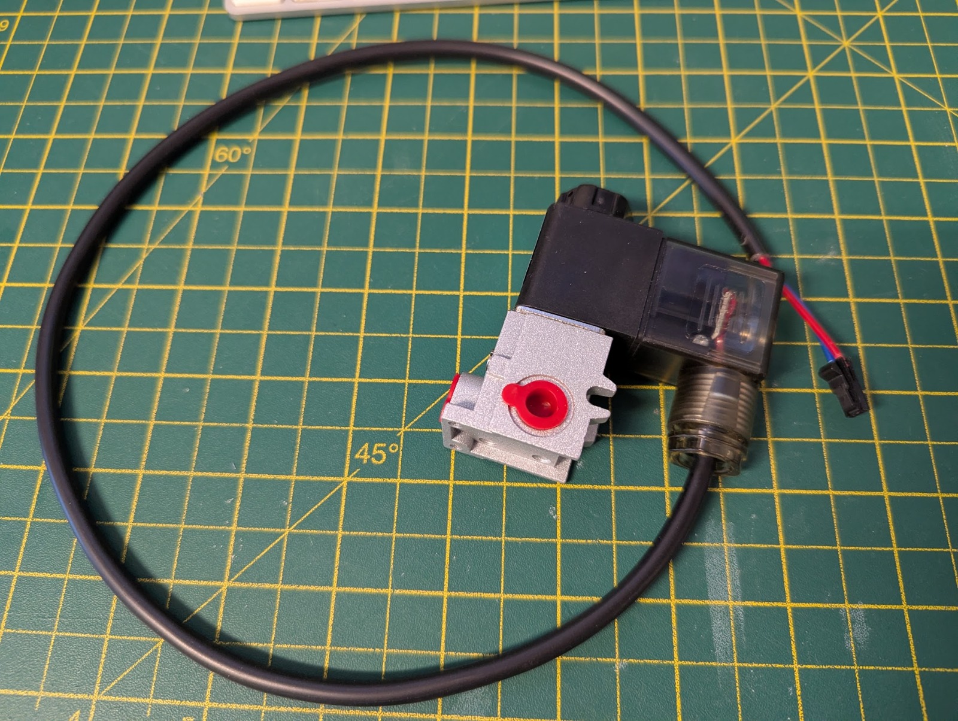
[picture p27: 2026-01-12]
Components/CO2 transfer/VentingSolenoid.jpeg

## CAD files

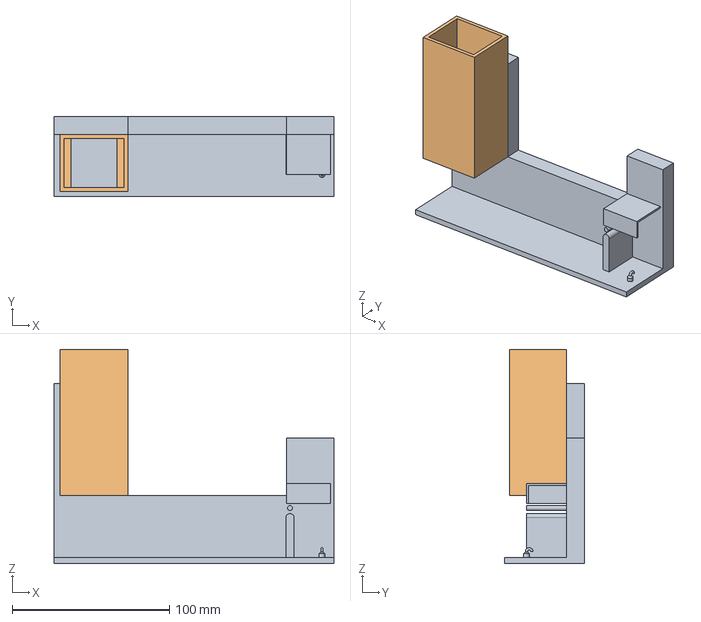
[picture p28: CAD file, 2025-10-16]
PastResearch/HMC-Clinic/ValveTeamFiles/Valve Main Body.step
177.8 x 50.8 x 136.0 mm

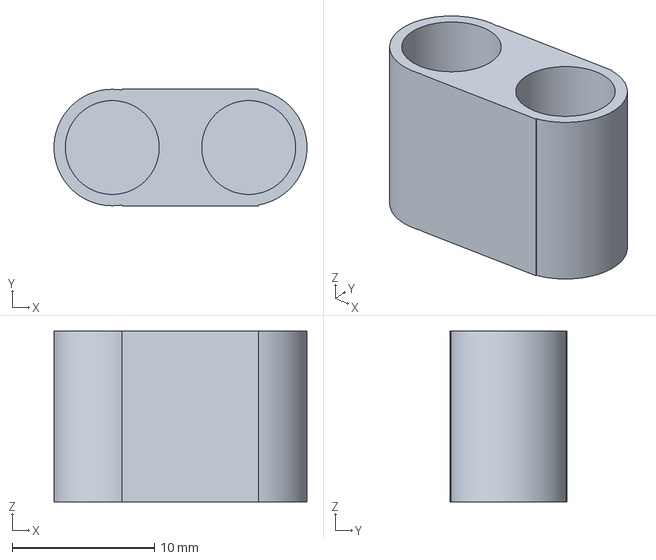
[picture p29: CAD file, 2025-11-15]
Components/ElectrodeTopStop/ElectrodeTopStop.3mf
17.8 x 8.20 x 12.0 mm

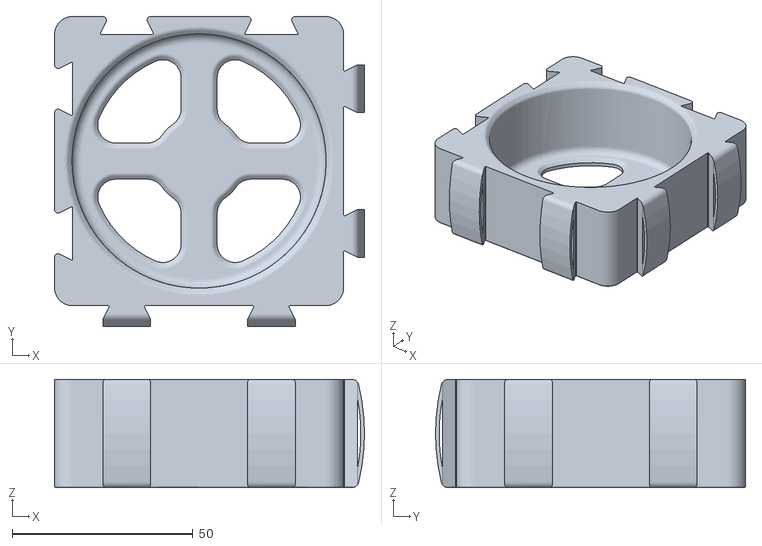
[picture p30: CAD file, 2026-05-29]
Components/GL45BottleHolder/GL45_holder_250ml.stl
85.8 x 85.8 x 30.0

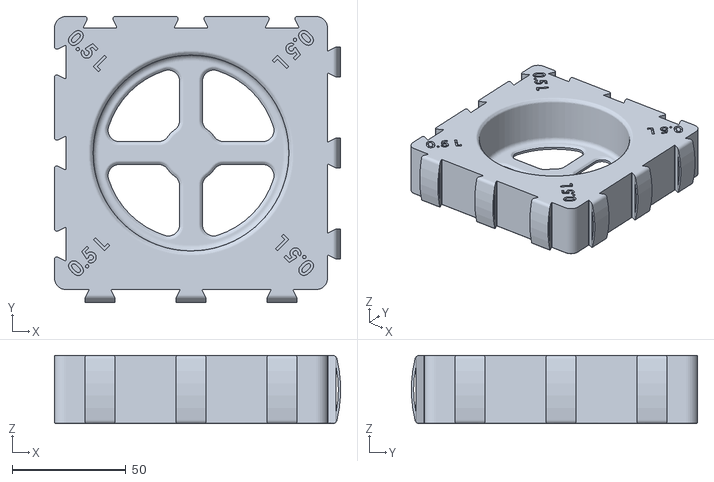
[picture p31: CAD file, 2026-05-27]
Components/GL45BottleHolder/source/duran_holder_platform_center_0.5L.stl
125.7 x 125.7 x 30.0

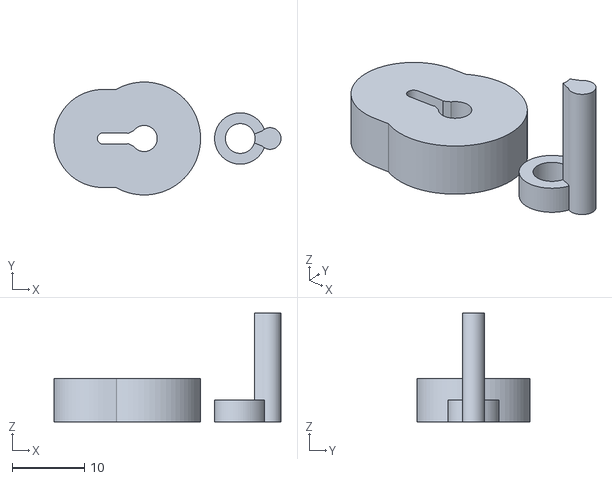
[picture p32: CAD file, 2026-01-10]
Components/PinchSlider/PinchSlider.stl
31.3 x 15.6 x 15.0

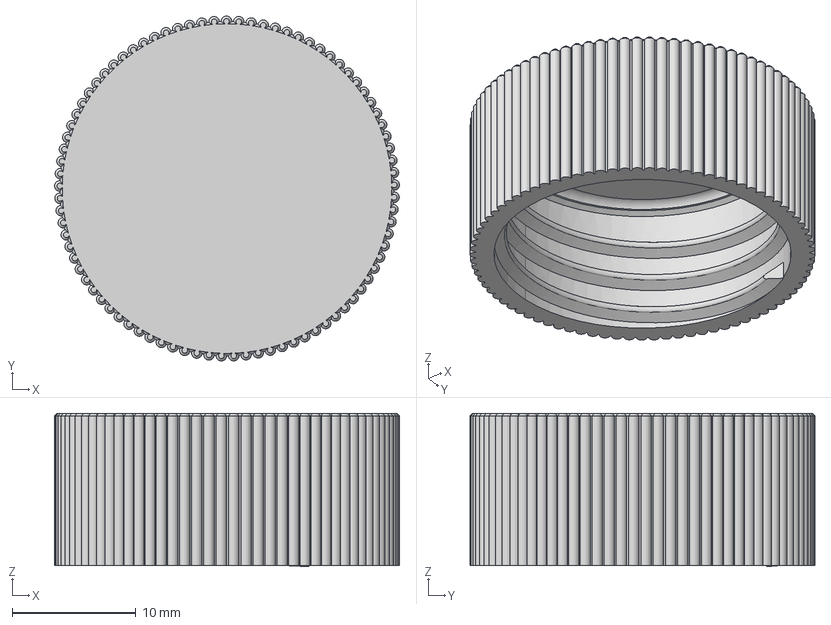
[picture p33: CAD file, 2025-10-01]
Components/Vial Cap/0 ports/Pioreactor (Canada) official/blank_vial_cap.step
27.9 x 27.8 x 12.4 mm

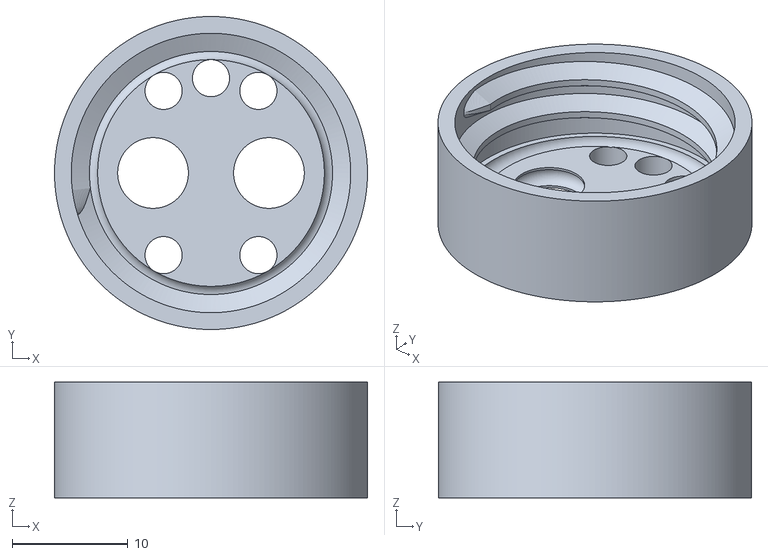
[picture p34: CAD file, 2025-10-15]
Components/Vial Cap/2x6.1 + 5x3.2mm ports/Vial Cap 2x6.1 + 5x3.2 v2.stl
27.0 x 27.0 x 10.0

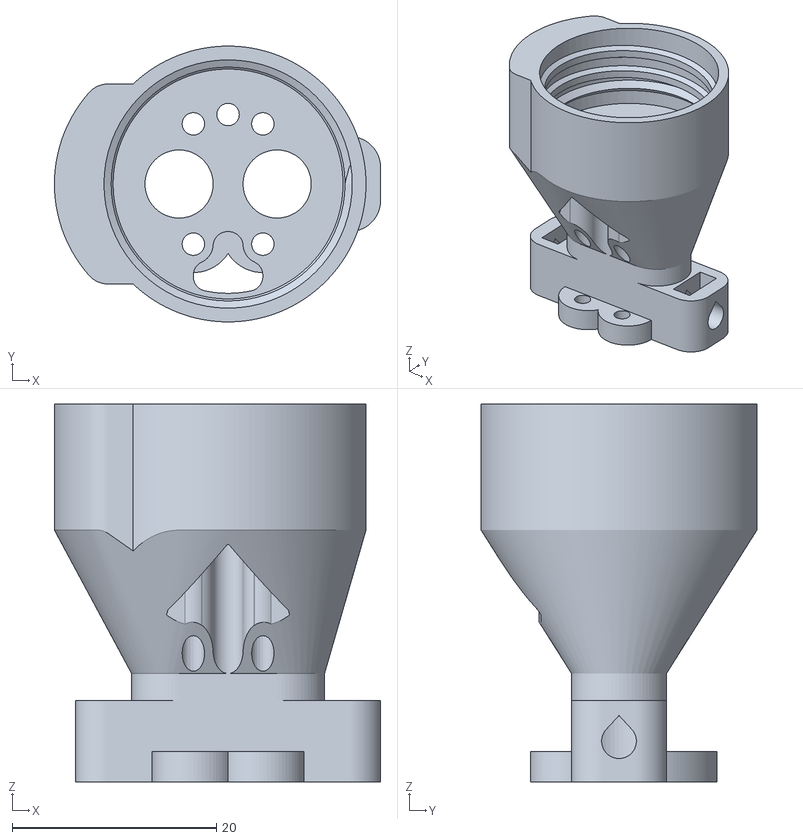
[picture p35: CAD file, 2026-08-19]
Components/Vial Cap/AEP2.0/Vessel Cap.stl
31.9 x 27.0 x 37.0

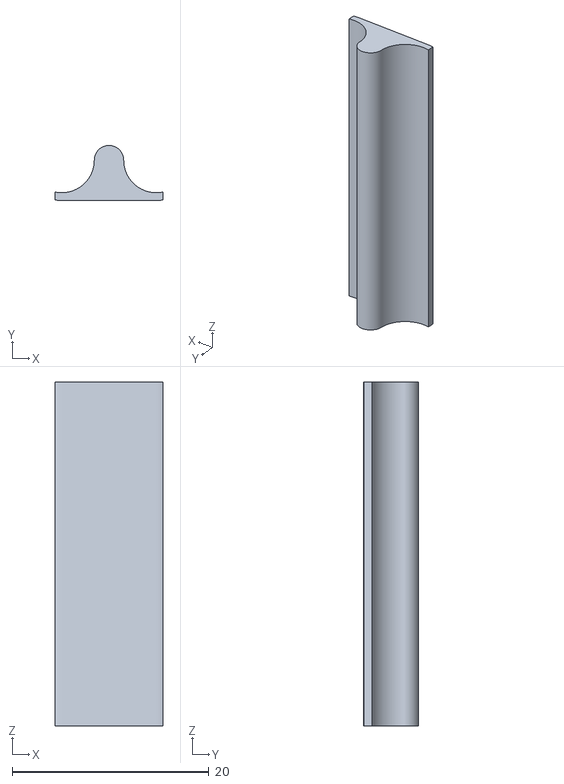
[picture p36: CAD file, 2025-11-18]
Components/x Redundant/ElectrodeSeatingGuide/ElectrodeSeatingGuide.stl
11.0 x 5.60 x 35.0

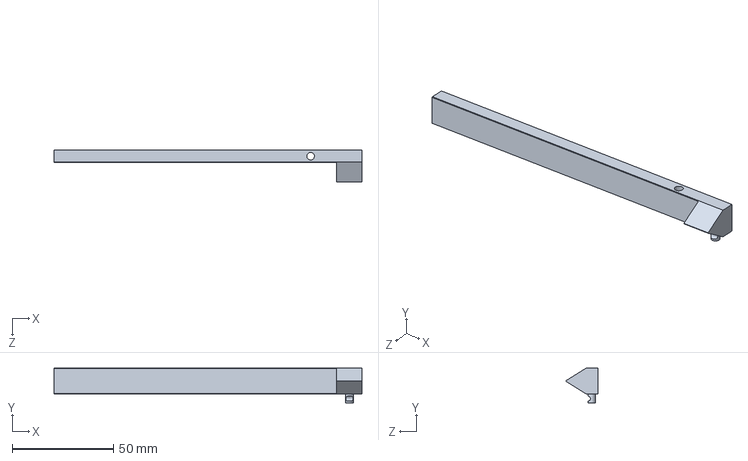
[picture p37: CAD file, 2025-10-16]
PastResearch/HMC-Clinic/ValveTeamFiles/valve pincher.sldprt
152.4 x 17.1 x 16.0 mm

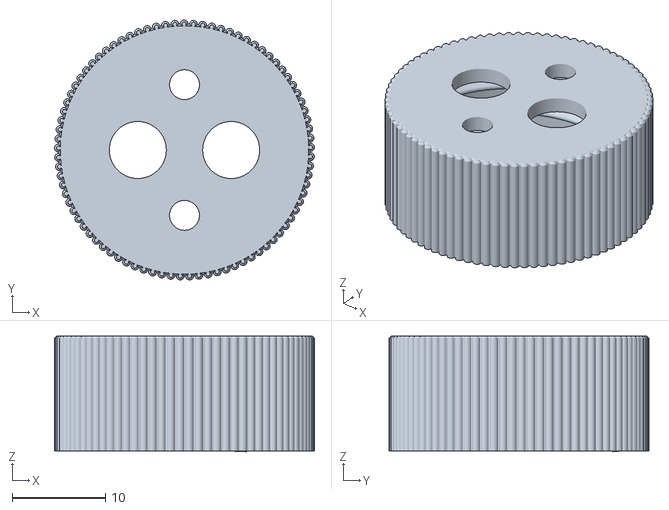
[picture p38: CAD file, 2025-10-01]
Vial Caps/2x6.1 + 2x3.2mm ports/6mm_cap_v2.stl
27.8 x 27.8 x 12.4

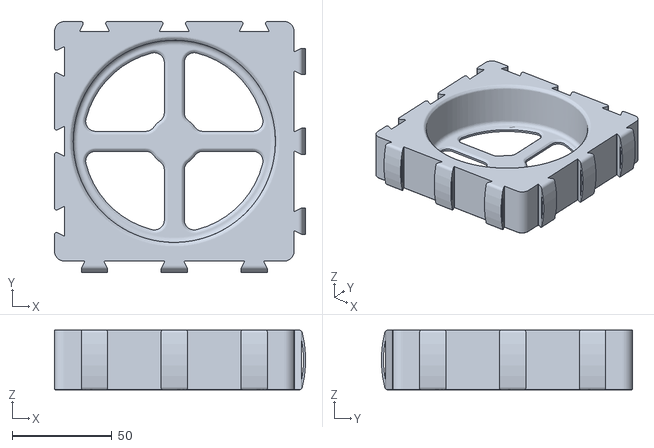
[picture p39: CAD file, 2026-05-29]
Components/GL45BottleHolder/GL45_holder_1000ml.stl
125.7 x 125.7 x 30.0

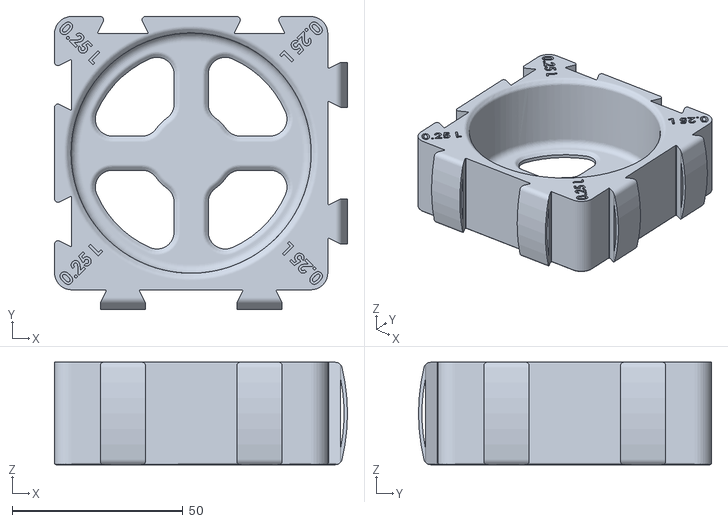
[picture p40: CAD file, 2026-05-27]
Components/GL45BottleHolder/source/duran_holder_platform_center_0.25L.stl
85.8 x 85.8 x 30.0

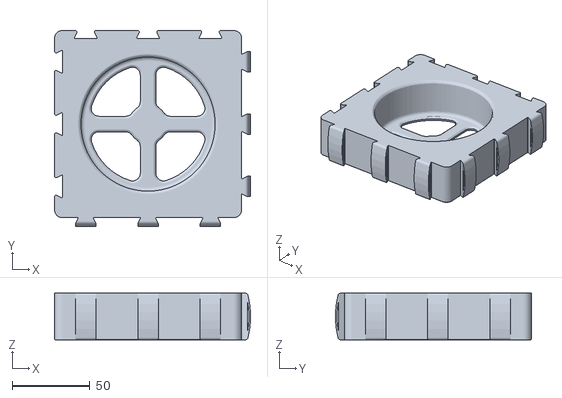
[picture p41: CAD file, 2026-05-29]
Components/GL45BottleHolder/GL45_holder_500ml.stl
125.7 x 125.7 x 30.0

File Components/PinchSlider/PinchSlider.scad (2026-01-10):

// Input parameters
TubingOD = 3; // tubing outer diameter
TubingPinched = 1.5; // tubing thickness when fully pinched
TubingUnits = "mm"; // units of input parameters: "inches" or "mm"

// Design parameters
SlotRatio = 3; // ratio of slot length to width
OpenTolerance = 0.6; // outer diameter print tolerance in mm
ClosedTolerance = 0.05; // closed slot print tolerance in mm
Margin = 2; // multiple of TubingOD to use as printed area around slot
BridgeApexFraction = 0.6; // 0–1 along closed slot length from its far end toward the open slot: larger values give a bigger bump to retain tubing in closed position
BungDepthMultiplier = 2.5; // bung is this many times deeper than body depth
TubeHoleTolerance = TubingOD/6 + OpenTolerance; // clearance for tubing through bung

// Calculated parameters
conversionFactor = (TubingUnits == "inches") ? 25.4 : (TubingUnits == "mm") ? 1 : undef;
TubingODc = TubingOD * conversionFactor; // Tubing outer diameter in mm
TubingCompressed = TubingPinched * conversionFactor; // compressed tubing wall thickness in mm
OpenWidth = TubingODc + OpenTolerance; // open slot width in mm
ClosedWidth = TubingCompressed + ClosedTolerance; // closed slot width in mm
OpenLength = OpenWidth; // open slot length in mm
ClosedLength = SlotRatio * ClosedWidth; // closed slot length in mm
MarginMM = Margin*TubingODc; // margin distance in mm
ThinBodyLength = ClosedLength + 2*MarginMM; // thin body length in mm (margin each end)
ThinBodyWidth = ClosedWidth + 2*MarginMM; // thin body width in mm (margin each side)
OpenBodyDiameter = OpenWidth + 2*MarginMM; // thick body diameter in mm
OpenBodyRadius = OpenBodyDiameter/2;
Depth = MarginMM; // body depth in mm
BridgeBaseLength = OpenWidth; // base length of connecting triangle
BungTolerance = OpenTolerance; // clearance on bung profile to allow insertion
CollarThickness = max(MarginMM/4, 1); // collar wall thickness around tubing
CollarHeight = Depth/2; // collar height
BungOffset = OpenLength/2 + OpenBodyRadius + MarginMM + max(BridgeBaseLength/2, OpenWidth/2); // place bung one margin away

$fn = 64;

// 2D capsule used for rounded bodies and slots
module capsule2d(length, width) {
  r = width/2;
  hull() {
    translate([r, 0]) circle(r = r);
    translate([length - r, 0]) circle(r = r);
  }
}

// Centered capsule helper
module capsule2d_centered(length, width) {
  translate([-length/2, 0]) capsule2d(length, width);
}

// Bung 2D profile (triangle + circle) with configurable clearance
module bung_profile_2d(tol = 0) {
  baseLen = max(BridgeBaseLength - tol, tol);
  circleD = max(OpenWidth - tol, tol);
  apexX = -ClosedLength + ClosedLength*BridgeApexFraction;
  union() {
    translate([OpenLength/2, 0]) circle(d = circleD);
    polygon(points = [
      [apexX, 0],
      [OpenLength/2, -baseLen/2],
      [OpenLength/2,  baseLen/2]
    ]);
  }
}

// Bung solid with retaining collar
module bung() {
  holeD = TubingODc + TubeHoleTolerance;
  holeR = holeD/2;
  collarOuterR = holeR + CollarThickness;
  bungDepth = BungDepthMultiplier * Depth;
  collarX = -ClosedLength/2; // centered on midpoint of closed slot

  difference() {
    union() {
      linear_extrude(bungDepth)
        bung_profile_2d(BungTolerance);

      translate([collarX, 0, 0])
          cylinder(h = CollarHeight, r = collarOuterR, center = false);
    }

    // Through-hole for tubing
    translate([collarX, 0, -1])
      cylinder(h = bungDepth + CollarHeight + 2, r = holeR, center = false);
  }
}

// -----------------------------
// Model
// -----------------------------
module pinch_slider_body() {
  difference() {
    // Body
    linear_extrude(Depth) {
      union() {
        translate([-ClosedLength/2, 0])
          capsule2d_centered(ThinBodyLength, ThinBodyWidth);
        translate([OpenLength/2, 0])
          circle(r = OpenBodyRadius);
      }
    }

    // Slot
    translate([-ClosedLength/2, 0, 0])
      linear_extrude(Depth)
        capsule2d_centered(ClosedLength, ClosedWidth);

    // Triangular cutout joining far closed end to open center
    linear_extrude(Depth)
      polygon(points = [
        [-ClosedLength + ClosedLength*BridgeApexFraction, 0], // apex along closed slot
        [OpenLength/2, -BridgeBaseLength/2],
        [OpenLength/2,  BridgeBaseLength/2]
      ]);

    // Open slot is now a circular cutout
    translate([OpenLength/2, 0, 0])
      cylinder(h = Depth, d = OpenWidth, center = false);
  }
}

// Assemble body and bung with spacing
pinch_slider_body();
translate([BungOffset, 0, 0]) bung();

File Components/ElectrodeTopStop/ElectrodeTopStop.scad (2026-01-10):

// Electrode Top Stop
// Racetrack-shaped cover that keeps the two electrodes parallel and seated
// to a consistent depth. Only the top is open, so the bottom face stops each
// electrode at the same height while also sitting flat on the print bed.
// Modified from Vial Cap.scad by Codex, then hand fixed.

$fn = 160; // smooth cylinders for a better fit

// -----------------------------
// Key parameters
// -----------------------------
electrode_od = 6.0;        // mm, outer diameter of electrode
electrode_tol = 0.6;       // mm, print clearance on each electrode hole
electrode_cutout = 0;      // mm, additional clearance used on the cap
electrode_offset = 4.8;    // mm, distance from origin to each electrode center

stop_height = 12;           // mm, overall height of the figure-eight stop
stop_cap_thickness = 2;    // mm kept solid on top to create the stop surface
shell_wall = 0.8;          // mm extra wall around each electrode sleeve

m3_nut_od = 5.8;
wall = 1.3;
m3_nut_holder_width = m3_nut_od + wall;
m3_nut_width = 2.5;
m3_bolt = 3.1;


// Derived dimensions
electrode_port_od = electrode_od + electrode_tol + electrode_cutout;
outer_shell_od = electrode_port_od + 2 * shell_wall;
stop_hole_depth = stop_height - stop_cap_thickness;
assert(stop_cap_thickness < stop_height, "stop_cap_thickness must be less than stop_height");

// -----------------------------
// Helper modules
// -----------------------------
module electrode_shell(height) {
  union() {
    // Cylindrical sleeves around each electrode port
    for (offset = [-electrode_offset, electrode_offset])
      translate([-offset, 0, 0])
        cylinder(d = outer_shell_od, h = height, center = false);

    // Rectangular bridge that closes the sleeves into a racetrack profile
    translate([- electrode_offset, -outer_shell_od / 2, 0])
      cube([2 * electrode_offset, outer_shell_od, height], center = false);
  }
}

// -----------------------------
// Model
// -----------------------------
difference() {
  hull() {
    electrode_shell(stop_height);
    
    // Nut holders
    for (offset = [-1.4, 1])
      translate([offset * (outer_shell_od + wall), -m3_nut_holder_width / 2, 0])
        cube([m3_nut_width + wall, m3_nut_holder_width, stop_height]);
  }
  
  // Nut traps
  for (offset = [-1.3, 1])
      translate([offset * (outer_shell_od + wall), -m3_nut_od/2, -5])
        cube([m3_nut_width, m3_nut_od, stop_height]);
    
  // Wire holes
  for (offset = [-1.2, 1])
      translate([offset * (outer_shell_od - 1), -m3_bolt/2, 0])
        cube([1, m3_bolt, stop_hole_depth]);
  
  // Bolt holes
  for (offset = [-1, 1])  
      translate([offset * electrode_offset, 0, m3_nut_holder_width/2])
        rotate([offset * 90, 0, 90])
          cylinder(15, d = m3_bolt);

  // Openings for the electrodes from the top only
  for (offset = [-electrode_offset, electrode_offset])
    translate([-offset, 0, stop_cap_thickness])
      cylinder(d = electrode_port_od, h = stop_hole_depth, center = false);
}

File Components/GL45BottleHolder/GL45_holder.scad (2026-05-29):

// GL45BottleHolder – Pioreactor dovetail GL45 bottle holder
//
// The upstream Duran holders (e.g. Printables 1058356) have lettering
// cut into the four corners. Those recessed letter shapes trap residue
// and are awkward to clean. This SCAD imports the chosen upstream holder
// and fills its corner lettering with smooth caps, leaving the rest of
// the geometry untouched.
//
// Pick the bottle size below, then render (F6) and export the STL.

// ---- selector ----------------------------------------------------------
bottle_ml = 250;   // [250, 500, 1000]

// ---- source holders ----------------------------------------------------
// 250 ml is an 85.75 mm square platform; 500 ml and 1000 ml share a larger
// 125.7 mm square platform, but their corner labels ("0.5 L" vs "1 L") sit
// in slightly different spots, so each size has its own cover positions.
function source_file(ml) =
      ml == 250  ? "./source/duran_holder_platform_center_0.25L.stl"
    : ml == 500  ? "./source/duran_holder_platform_center_0.5L.stl"
    : ml == 1000 ? "./source/duran_holder_platform_center_1L.stl"
    : undef;

// ---- corner cover positions  [x, y, angle] -----------------------------
// Each cover is a stadium (a rectangle with semicircular ends) laid along the
// corner->centre diagonal so it hugs the diagonal text run. The rounded ends
// keep the cap inside the platform outline near the chamfered corners, so no
// overhang and no clipping are needed. x,y are each cap's centre and the third
// value is its angle; all sit on the 45/135 corner diagonals. Positions were
// dialled in by eye against the rendered holders.

// 250 ml: centres are Gerrit's verified positions (its 0.25 mm-deep engraving
// is too shallow to remeasure).
covers_250 = [
    [ 7.75, 13.00,  45],   // bottom-left
    [72.25, 78.00,  45],   // top-right
    [ 7.80, 77.95, 135],   // top-left
    [72.40, 13.55, 135]    // bottom-right
];

// 500 ml: positions tuned by eye against the rendered 0.5 L holder.
covers_500 = [
    [ 15.5,  21.0,  45],   // bottom-left
    [105.0, 111.0,  45],   // top-right
    [ 15.5, 111.0, 135],   // top-left
    [105.0,  21.0, 135]    // bottom-right
];

// 1000 ml: positions tuned by eye against the rendered 1 L holder.
covers_1000 = [
    [ 12.3,  18.0,  45],   // bottom-left
    [107.7, 113.5,  45],   // top-right
    [ 12.2, 113.5, 135],   // top-left
    [108.0,  18.0, 135]    // bottom-right
];

function covers(ml) =
      ml == 250 ? covers_250
    : ml == 500 ? covers_500
    : covers_1000;

// ---- cap size ----------------------------------------------------------
// len = tip-to-tip along the text, wid = across it (= diameter of the rounded
// ends). 250 ml matches the proven cover envelope (~1.3 mm inside the edge);
// 500/1000 ml sit 12-18 mm in from every edge, so their caps are sized
// generously to swallow the label plus a few mm of measurement slack with minimal
// risk of overhang. Holders are 30 mm tall, so a 30 mm cap is full height.
cover_margin = 1.05;   // 5% extra on every cap X-Y dimension for positioning headroom
cover_len = ((bottle_ml == 250) ? 15 : (bottle_ml == 500) ? 21 : 14) * cover_margin;
cover_wid = ((bottle_ml == 250) ? 8 : (bottle_ml == 500) ? 10 : 10) * cover_margin;

$fn = 48;   // smooth rounded ends

// Full-height (0..30 mm) so the cap top is flush with the platform surface.
module cover(angle) {
    rotate([0, 0, angle])
    hull()
        for (s = [-1, 1])
            translate([s * (cover_len - cover_wid) / 2, 0, 0])
                cylinder(h = 30, d = cover_wid);
}

// ---- build -------------------------------------------------------------
import(source_file(bottle_ml));
for (c = covers(bottle_ml))
    translate([c[0], c[1], 0]) cover(c[2]);

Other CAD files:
Components/Vial Cap/Vial Cap.stl
Vial Caps/2x6.1 + 5x3.2mm ports/vial_cap_2x6.1+5x3.2_ports.step
Vial Caps/2x6.1 + 6x3.2mm ports/vial_cap_2x6.1_6x3.2_ports.step
Components/GL45BottleHolder/source/duran_holder_platform_center_1L.stl
Components/Vial Cap/Vial Cap.scad
Components/ElectrodeTopStop/ElectrodeTopStop.stl
Components/Vial Cap/2x6.1 + 2x3.2mm ports/Superseded/6mm_cap_v2.scad
Components/Vial Cap/2x6.1 + 5x3.2mm ports/Superseded/vial_cap_2x6.1+5x3.2_ports.3mf
Components/Vial Cap/2x6.1 + 5x3.2mm ports/Superseded/vial_cap_2x6.1+5x3.2_ports.step
Components/Vial Cap/2x6.1 + 5x3.2mm ports/Superseded/vial_cap_2x6.1+5x3.2_ports.stl
Components/Vial Cap/2x6.1 + 6x3.2mm ports/Superseded/vial_cap_2x6.1_6x3.2_ports.step
Components/Vial Cap/2x6.1 + 6x3.2mm ports/Superseded/vial_cap_2x6.1_6x3.2_ports.stl
Components/x Redundant/ElectrodeSeatingGuide/ElectrodeSeatingGuide.scad
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

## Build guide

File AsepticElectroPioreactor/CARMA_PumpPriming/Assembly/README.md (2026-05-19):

# Aseptic electroPioreactor AEP0.1.1 Assembly instructions

## Before you start

1. Procure Bill of Materials (TBD - contact us or [Labcrafter](https://labcrafter.co.uk) for AEP0.1.1 BoM)
2. Check your HOB are growing happily heterotrophically.

## Required Tools

1. Computer with SD card reader
2. microSD to SD adapter
3. Phillips PH0 Screwdriver
4. 28mm Gas cylinder wrench
5. Vernier Callipers
6. Analytical balance for pump calibration (Pioreactor docs only require 0.1g accuracy)
7. Cryogenic gloves (safe to at least -80°C)
8. Eye/face protection
9. Lab coat
10. Other PPE as directed by your supervisor/department/employer/H&S advisor

## Recommended Tools

1. Multitool and/or needle nose pliers (for general assembly and tubing adjustment)
2. Multimeter (for checking electrolysis)
3. Banded oil filter wrench (for CO2 canister tightening)

## Method

1. Connect empty dovetail platforms in raft, with dovetails always to front and left
   1. SodaStream at rear with expansion gap to right.
   2. 250ml duran product bottle in front and to the left of the SodaStream.
   3. 250ml duran media bottle in front and to the right of the SodaStream. (alternate media and waste if multiple AEPs, forming a backbone of media bottle dovetail platforms)
   4. Peristaltic pumps in front of product bottle
   5. Pioreactor in front of Peristaltic pumps
   6. The setup should look like this:


2. Follow relevant Pioreactor hardware setup guide: <https://docs.pioreactor.com/user-guide/20ml-v11-hardware-setup-intro>
   1. If using solenoid for sparging you will need more power, follow instructions here: <https://docs.pioreactor.com/user-guide/external-power>
4. Follow relevant Pioreactor software setup guide: <https://docs.pioreactor.com/user-guide/software-set-up>
5. Set up electrolysis (NOTE: ~struck through~ lines will already have been completed if you received a kit from Labcrafter)
   1. ~Insert electrode o-rings into the [Vial Cap](../Components/Vial%20Cap)~
   2. ~Insert electrodes half-way into Vial Cap using a twisting motion to avoid dislodging the o-rings~
   3. ~Push electrodes fully into their [Electrode Top Stop](../Components/ElectrodeTopStop)~
   4. ~Connect red electrode cable to platinum plated anode by tightening M3 bolt through captive nut~
   5. ~Connect black electrode cable to stainless steel cathode by tightening M3 bolt through captive nut~
   6. ~Push down the Electrode Top Stop until the electrodes are at the standard depth <!-- TODO: Agree standard depth and produce protocol to repeatably attain it | assignee: @Bingqiao @Amir @Teo @Martin -->~
   7. Add nutrient solution (or equal ionic strength bicarbonate) to the Vial
   8. Fully screw the Vial Cap onto the Vial <!-- TODO: Agree standard depth and insert protocol to attain it using callipers | assignee: @Bingqiao @Amir @Teo @Martin -->
   9. The electrodes should now protrude into the vial to the standard depth
   10. If necessary, adjust the electrodes to the standard depth
   11. Record the distance from the plane of the top of the Vial Cap to the bottom of each electrode.
   12.  Connect the electrodes to LED channel D (catch upwards)
   13.  With electrolyte solution in the Vial, check electrolysis by setting the LED channel D intensity to 3%, and verifying that roughly twice as many bubbles are forming on the cathode
   14.  Record the voltage across each electrode, and the current through the electrodes, adjust the LED channel D intensity to attain standard values if necessary
   15.  Insert vial into Pioreactor once satisfied all vials have even electrolysis
6. Set up nutrient solution flow
   1. Follow Pioreactor peristaltic pump setup guide: <https://docs.pioreactor.com/user-guide/using-pumps>
   2. Follow the Pioreactor guide to attaching a 12V power supply: <https://docs.pioreactor.com/user-guide/external-power>
   3. Calibrate peristaltic pumps as per <https://docs.pioreactor.com/user-guide/hardware-calibrations#pump-calibration>
   4. Weigh dry empty vial
   5. Fill vial with DI water via the pumps, then weigh vials and adjust tube lengths until vial volume is 15ml
   6. Measure electrodes immersion depths, if necessary adjust to the standard, and record the insertion depth of each electrode
   7. Set up Pioreactor in turbidostat mode: <https://docs.pioreactor.com/user-guide/dosing-automations#turbidostat>
7. Set up carbon dioxide sparging
   1. Unscrew John-Guest push-fit output from the regulator outlet port


   2. Insert 8mm ID 2mm CS o-ring into the regulator outlet port


   3. Screw in the 1/4" male to 1/8" male reducer to the regulator outlet port and tighten with wrench.


   4. Cut a rectangle of gas PTFE tape to wrap around 1/8" male outlet thread 1.5 times.
   5. Wrap gas PTFE tape around 1/8" male outlet thread 1.5 times.
   6. Screw left port of the solenoid valve (with solenoid electronics to rear) into 1/8" male outlet. Ensure solinoid manual overide is closed (horizontal line pointing at 0 on the front on the solinoid).


   7. Cut a rectangle of gas PTFE tape to wrap around needle valve inlet thread (the bare metal thread opposite the screw adjustor) 1.5 times.
   8. Wrap gas PTFE tape around needle valve inlet thread 1.5 times.
   9. Screw needle valve into 1/8" front port of solenoid valve
   10. Close needle valve clockwise
   11. Cut a rectangle of gas PTFE tape to wrap around 1/8" male blanking plug thread 1.5 times.
   12. Wrap gas PTFE tape around 1/8" male blanking plug thread 1.5 times.
   13. Screw male blanking plug thread into right port of solenoid valve and tighten with wrench.
   14.  Close regulator (turn flathead screw fully anti-clockwise)
   15.  Move plastic washer attached to regulator to between regulator and SodaStream adapter
   16.  Sit second plastic washer on top of SodaStream cylinder
   17. **Important:** (while remembering to don all PPE including cryogenic gloves prior to tightening cylinder in one swift, decisive move) [**follow instructions included with SodaStream adapter**](https://cdn.shopify.com/s/files/1/2268/6279/files/BrewKegTap_Sodastream_Adapter_Instructions.pdf?v=1763549894)
   18. Place SodaStream in dovetail raft
   19. Remove compression nut from the top of the needle valve
   20. Attach the 4mm tubing to the needle valve ferrule - dip in hot water to soften if necessary
   21. Reattach the compression nut
   22. Attach the male end of an 0.2 μm vent filter to the female luer lock on the vial CO₂ entry port
   23. Attach the female ends of two 0.2 μm vent filters to the two male luer locks on the vial exhaust ports
   24. Cut the 4mm tubing just long enough to run over the regulator and down to the CO₂ entry filter
   25. Measure the 4mm tubing cut length and ensure all other 4mm tubing is cut to the same length
   26. Insert a 1/8" (or 5/32" if 1/8" too loose) barb hose to male luer lock adapter in the free end of the 4mm tubing - dip in hot water to soften if necessary
   27. Connect the luer lock to the CO₂ entry filter
   28. Connect the solenoid connector to PWM channel 4 on the Pioreactor.
8. Set up software for sparging
   1. [Install](https://docs.pioreactor.com/user-guide/using-community-plugins#installing-plugins) the `pioreactor-relay-plugin` plugin.
   2. In your Pioreactor configuration, make sure that PWM channel 4 is set to `relay`:
   ```
   [PWM]
   # map the PWM channels to externals.
   # hardware PWM are available on channels 1 & 3.
   1=stirring
   2=waste
   3=media
   4=relay
   5=heating
   ```
   3. Test that it works by manually turning on the relay in the **Activities** tab of the *Manage* screen of the Pioreactor UI. You should hear the solenoid turn on and CO2 rushing into the Pioreactor vial. You can adjust the amount of CO2 sparged using the needle valve (for consistency maintain regulator pressure at 1 bar).

      

   4. Create a new [experiment profile](https://docs.pioreactor.com/user-guide/experiment-profiles) and copy and paste the following into the profile:
   ```yaml
   experiment_profile_name: CO2 sparging every hour
   
   metadata:
     author: Gerrit Niezen
     description: Turns on the relay for 10 seconds every hour
   
   common:
     jobs:
       relay:
         actions:
           - type: repeat
             hours_elapsed: 1.0
             repeat_every_hours: 1.0
             actions:
               - type: log
                 hours_elapsed: 0.0  # relative to the repeat loop, 1h
                 options:
                   message: "Sparging CO2 for 10 seconds"
                   level: info
               - type: start
                 hours_elapsed: 0.0
                 options:
                   start_on: True
               - type: stop
                 hours_elapsed: 0.00278
   ```
   When the experiment profile is running it should sparge CO2 for 10 seconds every hour.
9. Calibrate CO₂ flow
    1. Set regulator to 1 bar
    2. Adjust needle valve to give target flow rate
    3. To start sparging, turn on the relay in the Pioreactor UI
    4. Temporarily close one of two outlet gas vents with luer plug
    5. Run 1/16" tubing from outlet of open gas vent port to bath until water CO2 concentration is assumed (or if possible measured) to have equilibrated
    6. Record time taken to fill measuring cylinder with CO₂ over water
    7. Determine the actual flow rate
    8.  Adjust needle valve and repeat process until target flow rate is achieved
10. Sterilise
    1. <!-- TODO: PI's to approve process in accordance with departmental requirements | assignee: @Amir @Teo @Bingqiao @Chris @Sonja -->

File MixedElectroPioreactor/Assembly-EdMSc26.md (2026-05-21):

# MEP Assembly (Edinburgh MSc)

You will assemble two MEP0.3 units: **ed04** and **ed05**. Both arrive with microSDs flashed and the FZone-HPControl CO₂ regulator-solenoid stack pre-built by Martin.

ed04 is the unit that gets a bagged Pt-plated Ti anode and stainless steel cathode which you can unwrap and install once you are comfortable using ed05. ed05 has all the newest other parts; its electrodes are already installed from bench testing.

## PPE

- Eye / face protection
- Lab coat
- Gloves for media handling

## Layout

1. Setup a mobile phone hotspot with SSID AMYBO and password raspberry.
2. Place the dovetail raft on the bench with dovetails to front and left.
3. Familiarise yourself with the raft.  At the rear we have the SodaStream cylinder with the right angle pin screw adapter on top, the CO₂ regulator is on top and to the front of this, it's left dial shows the SodaStream pressure (advanced warning that you're running out of CO2) and the right dial shows the pressure reaching the solenoid.  The solenoid is attached to the right of the regulator, with a lead connecting to PWM4, the needle valve comes out of the front of the solenoid.  In front of the SodaStream Cylinder we have the product container to the left of the media container, with their respective peristaltic pumps in front of them, then the electroPioreactor at the very front.
4. Connect the black 12 V PSU to the Pioreactor HAT's barrel jack connector and the white 5V Raspberry Pi PSU to the micro-USB socket on the Raspberry Pi (the frontmost socket on the bottom PCB if the Pioreactor Logo is facing you). The electroPioreactor should boot within ~90 s.
5. From a laptop connected to the mobile phone hotspot, open `http://ed04.local/` (or `http://ed05.local/`). Confirm the unit appears in the cluster view.

## Vial and PWM connections (both units)

1. Add 2M bicarbonate solution (or [MC02](https://github.com/amy-bo/electroPioreactor/tree/main/Media) medium) to the vial.
2. Screw the Vial Cap fully onto the vial.
3. Seat the vial in the Pioreactor.

**PWM channel assignment for these units:**
PWM 2 = waste pump, PWM 3 = media pump. If you read [Pioreactor's pump documentation](https://docs.pioreactor.com/user-guide/using-pumps) and see PWM 2 used as a media-pump example, ignore that — for ed04/ed05 stick with the canonical 2=waste, 3=media.

## Hand-off

Once both units are assembled, vials seated, and reachable on the network, move on to [Operation.md](Operation.md) for the walkthrough, then [Calibration.md](Calibration.md) for the practical.

## Electrodes (ed04 only – fresh anode)

ed05 has its Platinum Plated Ti anode and Stainless Steel cathode already installed; ed04 has some low grade graphite electrodes installed, these should be used for testing purposes only - sodium bicarbonate is recommended instead of [MC02](https://github.com/amy-bo/electroPioreactor/tree/main/Media) for these graphite electrodes, as [MC02](https://github.com/amy-bo/electroPioreactor/tree/main/Media) corroded them more rapidly.

Once you are confident in operation and ready to install ed04's Platinum Plated Ti anode and Stainless Steel cathode

1. Use a 2.5mm Hex key to gently unscrew the screws on the [TopStop](../Components/ElectrodeTopStop) (with the red and black wires), then gently remove the top stop.
2. Unscrew the vial from the cap and disconnect the tubing (take a photo first so you can remember how to reconnect it).
3. Very gently rotate the graphite electrodes up and out of the vial cap.
4. Ensure the vial cap electrode o-rings are correctly seated in the vial cap and that they stay there throughout the next step.
5. Unwrap the bagged stainless steel cathode.
6. Very very gently rotate and push the stainless steel up through the anode's o-ring (to loosen it, the stainless steel anode is fractionally smaller & less delicate) then gently rotate it back out.
7. Very very gently rotate and push the stainless steel up through the cathode's o-ring.
8. Unwrap the bagged Pt-plated Ti anode. Try to avoid touching the platinised section.
9. Very very gently rotate and push the anode into its o-ring in the Vial Cap.
10. Rotate and adjust the heights of both electrodes so their bases are 33mm below the bottom of the vial cap.
11. Ensure the wires are correctly located in the TopStop so they will come into firm contact with each electrode when the TopStop screws are tightened onto the electrode
12. Push the TopStop down fully onto the electrodes.
13. Tighten the **red** electrode cable onto the Pt-plated Ti **anode** using the M3 bolt through the captive nut.
14. Tighten the **black** electrode cable onto the stainless-steel **cathode** using the M3 bolt through the captive nut.
   - Polarity matters. Reversing red and black dissolves the stainless steel into solution.
15. Reconnect the tubing and screw the vial back into place

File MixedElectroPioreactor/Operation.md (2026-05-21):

# MEP Operation (Edinburgh MSc)

You can run the pioreactor in three main operating modes: **fed-batch**, **chemostat**, and **turbidostat**. The first is strictly *fed-batch* — though no liquid medium is added or removed, the macronutrients (CO₂ from the sparge, H₂ and O₂ from in-culture electrolysis) are continuously fed. For brevity we'll call it **batch** in the rest of this doc. All three modes use the same hardware: stirring on PWM 1, product/waste on PWM 2, media on PWM 3, CO₂ relay on PWM 4, electrolysis on LED D at 2.5 %.

This doc is read as a walkthrough first (the theory of what you're about to do), then executed as a procedure later in the day if time allows. Actual execution requires both units fully set up per [Calibration.md](Calibration.md): stirring, peristaltic pumps, **OD600** (per-unit standard curve, [Calibration § 3](Calibration.md#3-od-calibration)), vial level, CO₂ flow rate, and electrolysis V and I. The per-experiment **OD blank** is a separate step (see § 1 Batch step 4 below) and is not a substitute for the standard curve.

## Modes at a glance

| Mode | Media in? | Product/Waste out? | When you would use it |
|---|---|---|---|
| Batch | No | No | Watch a culture grow on a fixed media charge until something runs out |
| Chemostat | fixed rate | fixed rate | Hold steady-state with a constant dilution; cells reach a balance between growth and washout |
| Turbidostat | OD-triggered | OD-triggered | Hold steady-state at a target Optical Density (OD) by running media + product/waste when OD exceeds threshold |

## 1. Batch experiment

This is the simplest experiment and the best for initial culture growth. The vial is filled once, the experiment runs, you watch.

1. **Prepare the vial.**
   1. Confirm electrodes at standard depth and connected with correct polarity (red→Pt anode, black→SS cathode).
   2. Fill the vial with 14 ml of MC02 medium (the 1 ml of headroom accommodates the electrodes and sparging tube).
   3. Screw the vial cap down. Attach the vent filters: one on the CO₂ entry luer, two on the exhaust luers.
2. **Seat the vial** in the Pioreactor (pre-inoculation, for OD blanking).
3. **Set up the experiment** in the web UI.
   1. Create a new experiment, name it e.g. `ed04_batch_<date>` (or ed05).
   2. Assign ed04 (or ed05) to the experiment.
4. **Read the OD blank.** Run `od_reading` until the trace is stable; save the blank for this experiment. 26.4.x's `od_reading` will refuse to start with OD calibrations or fused estimators enabled if no blank exists for the experiment.
5. **Inoculate.** Add inoculum through one of the exhaust luers using a syringe. (No need to unseat the vial.)
6. **Start jobs**, in this order:
   1. **Stirring.** Confirm the fan engages and the stir bar is moving in the vial.
   2. **OD reading.** Resume/restart; the saved blank is now applied to the trace.
   3. **Electrolysis.** In electroPioreactor Advanced set LED D to 2.5 %. Watch for bubbles within 30 s.
   4. **CO₂ sparging.** Set up electroPioreactor Advanced to open the relay every hour for 3 s. The electroPioreactor plugin handles pausing electrolysis during each sparge.
7. **Watch.** OD should rise; voltage and current should drift slightly as ionic strength changes; cathode bubbles should remain visibly more numerous than anode bubbles. Record voltage regularly.
8. **End.** When OD plateaus or you reach your endpoint, stop electrolysis and the sparge profile (by stopping electroPioreactor), stop stirring. Sample the vial through an exhaust luer.
9. **Strip down.** Drain the vial, rinse with distilled water then sterilise.

## 2. Chemostat

A chemostat continuously dilutes the culture at a fixed rate. Cells either grow fast enough to keep up (steady state) or wash out (rate too high). Start here only after you have a successful batch run.

1. Set up exactly as in batch, through inoculation and seating the vial.
2. Configure the **dosing automation** in the Pioreactor UI:
   1. Mode: chemostat
   2. `exchange volume` (mL): e.g. 0.5
   3. `duration` (minutes): the interval between doses. Combined with `exchange volume`, this sets the dilution rate D (h⁻¹) = (`exchange volume` × 60 / `duration`) / 14, where 14 is the working volume in mL (see `efflux_tube_volume_ml`).
3. Start stirring, OD, electrolysis at 2.5 %, sparge profile, and chemostat dosing.
4. Watch OD over many hours: it will move toward a steady state if D is below the maximum specific growth rate, otherwise wash out.
5. End and strip down as for batch.

**Vial level:** Position the waste tube at your desired vial level before starting. The waste pump over-runs each dilution cycle by design; tube height is the level setpoint, not the media/waste volume ratio. See [forum #801](https://forum.pioreactor.com/t/dosing-volumes-how-to-keep-the-volume-added-and-the-volume-removed-to-be-equal/801) for an explanation.

## 3. Turbidostat

A turbidostat holds OD at a target by triggering media and product/waste pulses whenever OD exceeds threshold.

1. Set up as for chemostat, through inoculation and seating.
2. Configure the **dosing automation**:
   1. Mode: turbidostat
   2. `target biomass`: e.g. 0.5 (set as anticipated for the electrolysis/medium/strain combination)
   3. `biomass signal`: leave at `auto` unless you have reason to pick `normalized_od`, `od_fused`, or `od` explicitly.
   4. `exchange volume` (mL): 1.0–2.0 (Pioreactor's recommendation for fast-growing cultures); waste side is matched by the same dosing event.
3. Start the standard job set (stirring, OD, electrolysis, sparge profile) and the turbidostat dosing automation.
4. The unit pulses media + product/waste whenever OD crosses the target. OD trace becomes a sawtooth around the target.
5. End and strip down as for batch.

## Records

For each run, record in the Pioreactor software:

In the experimental setup dialogue:
- Experiment name, mode, unit, dates
- Media batch, inoculum source, inoculum volume
As you proceed:
- Voltage and current at start, voltage at least daily, ideally hourly, and at end
- Any anomalies: loose electrode connection at the Top Stop captive nut, bubble rate change, anode discolouration, vial level drift, Pioreactor knocked, etc.

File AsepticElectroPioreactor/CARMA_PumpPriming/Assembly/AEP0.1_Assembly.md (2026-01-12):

# Aseptic electroPioreactor AEP0.1 Assembly instructions

## Before you start

1. Procure Bill of Materials (TBD - contact us or [Labcrafter](https://labcrafter.co.uk) for AEP0.1 BoM)
2. Check your HOB are growing happily heterotrophically.

## Required Tools

1. Computer with SD card reader
2. microSD to SD adapter
3. Philips PH0 Screwdriver
4. 28mm Gas cylinder wrench
5. Cryogenic gloves (safe to at least -80°C)
6. Eye/face protection
7. Lab coat
8. Other PPE as directed by your supervisor/department/employer/H&S advisor
9. Analytical balance for pump calibration (Pioreactor docs only require 0.1g accuracy)

## Method

1. Connect empty dovetail platforms in raft, with dovetails always to front and left
   1. SodaStream at rear with expansion gap to right.
   2. 250ml duran product bottle in front of SodaStream
   3. 250ml duran media bottle to right of product bottle (alternate media and waste if multiple AEPs, forming a backbone of media bottle dovetail platforms)
   4. Peristaltic pumps in front of product bottle
   5. Pioreactor in front of Peristaltic pumps
2. Follow relevant Pioreactor hardware setup guide: <https://docs.pioreactor.com/user-guide/20ml-v11-hardware-setup-intro>
3. Follow relevant Pioreactor software setup guide: <https://docs.pioreactor.com/user-guide/software-set-up>
4. Set up electrolysis
   1. ~Insert electrode o-rings into the [Vial Cap](../Components/Vial%20Cap)~
   2. ~Insert electrodes half-way into Vial Cap using a twisting motion to avoid dislodging the o-rings~
   3. Push electrodes fully into their [Electrode Top Stop](../Components/ElectrodeTopStop)
   4. Temporarily place the [Electrode Seating Guide](../Components/ElectrodeSeatingGuide) on top of the Vial Cap between the electrodes
   5. Push down the Electrode Top Stop until it is flush with the Electrode Seating Guide which is flush with the top of the Vial Cap
   6. Add nutrient solution (or equal ionic strength phosphate/sulfate) to the Vial
   7. Fully screw the Vial Cap onto the Vial
   8. Without raising the Electrode Top Stop, slide out the Seating Guide
   9. The electrodes should now protrude into the vial to the standard depth
   10. If necessary, adjust the electrodes to the standard depth
   11. Record the distance from the plane of the top of the Vial Cap to the bottom of each electrode.
<<<<<<< HEAD
   12. Connect the platinised titanium electrode to the positive terminal of channel D on the Pioreactor with the red crocodile clip
   13. Connect the stainless steel electrode to the negative terminal of channel D with the black crocodile clip
   14. With electrolyte solution in the Vial, check electrolysis by setting the LED channel D intensity to 10%, and verifying that roughly twice as many bubbles are forming on the cathode
=======
   12. Connect the platinised titanium anode to the positive terminal of channel D on the Pioreactor with the red crocodile clip
   13. Connect the stainless steel cathode to the negative terminal of channel D with the black crocodile clip
   14. With electrolyte solution in the Vial, check electrolysis by setting the LED channel D intensity to 3%, and verifying that roughly twice as many bubbles are forming on the cathode
>>>>>>> eeeb4d6 (initial commit)
   15. Record the voltage across each electrode, and the current through the electrodes, adjust the LED channel D intensity to attain standard values if necessary
   16. Insert vial into Pioreactor once satisfied all vials have even electrolysis
5. Set up nutrient solution flow
   1. Follow Pioreactor peristaltic pump setup guide: <https://docs.pioreactor.com/user-guide/using-pumps>
   2. Calibrate peristaltic pumps as per <https://docs.pioreactor.com/user-guide/hardware-calibrations#pump-calibration>
   3. Weigh dry empty vial
   4. Fill vial with DI water via the pumps, then weigh vials and adjust tube lengths until vial volume is 15ml
   5. Measure electrodes immersion depths, if necessary adjust to the standard, and record the insertion depth of each electrode
   6. Set up Pioreactor in turbidostat mode: <https://docs.pioreactor.com/user-guide/dosing-automations#turbidostat>
6. Set up carbon dioxide sparging
   1. Unscrew John-Guest push-fit output from the regulator outlet port
   2. Insert 8mm ID 2mm CS o-ring into the regulator outlet port
   3. Screw in the 1.4" male to 1/8" female reducer to the regulator outlet port
   4. Cut a rectangle of gas PTFE tape to wrap around needle valve inlet thread (the bare metal thread opposite the screw adjustor) 1.5 times.
   5. Wrap gas PTFE tap around needle valve inlet thread 1.5 times.
   6. Screw needle valve into 1/8" female reducer
   7. Close needle valve clockwise
   8. Close regulator (turn flathead screw fully anti-clockwise)
   9. Move plastic washer attached to regulator to between regulator and SodaStream adapter
   10. Sit second plastic washer on top of SodaStream cylinder
   11. **Important:** (while remembering to don all PPE including cryogenic gloves prior to tightening cylinder in one swift, decisive move) [**follow instructions included with SodaStream adapter**](https://cdn.shopify.com/s/files/1/2268/6279/files/BrewKegTap_Sodastream_Adapter_Instructions.pdf?v=1763549894)
   12. Place SodaStream in dovetail raft
   13. Remove o-ring from bubble counter and place over needle valve outlet
   14. Screw bubble counter onto needle valve
   15. Unscrew metal cap from transparent bubble counter tube
   16. Add 2.5 ml (or 2.25 with old type [rounded compression nut, supplied with clear o-ring] bubble counter) of deionised water to the bubble counter
   17. Replace metal cap on transparent buble counter tube
   18. Remove compression nut from the top of the bubble counter
   19. Attach the 4mm tubing to the top of the bubble counter - dip in hot water to soften if necessary
   20. Reattach the compression nut
   21. Attach the male end of an 0.2 μm vent filter to the female luer lock on the vial CO₂ entry port
   22. Attach the female ends of two 0.2 μm vent filters to the two male luer locks on the vial exhaust ports
   23. Cut the 4mm tubing just long enough to run over the regulator so it keeps the bubble counter vertical and down to the CO₂ entry filter
   24. Measure the 4mm tubing cut length and ensure all other 4mm tubing is cut to the same length
   25. Insert a 1/8" (or 5/32" if 1/8" too loose) barb hose to male luer lock adapter in the free end of the 4mm tubing - dip in hot water to soften if necessary
   26. Connect the luer lock to the CO₂ entry filter
7. Calibrate CO₂ flow
    1. Set regulator to 1 bar
    2. Adjust needle valve to give say 30 bubbles per 10 seconds
    3. Wait for system to equilibrate
    4. Repeat from step 1 as needed
    5. Temporarily pinch one of the two gas vent ports closed
    6. Run 1/16" tubing from outlet of open gas vent port to bath until water CO2 concentration is assumed (or if possible measured) to have equilibrated
    7. Record time taken to fill measuring cylinder with CO₂ over water
    8. Determine the actual flow rate
    9. Adjust target bubble count and repeat process until target flow rate is achieved
8. Sterilise
    1. ***(PI's to determine process in accordance with departmental requirements)***

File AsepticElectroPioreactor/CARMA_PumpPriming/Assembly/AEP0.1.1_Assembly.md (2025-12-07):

Please see [README.md](README.md) for latest AEP version assembly instructions

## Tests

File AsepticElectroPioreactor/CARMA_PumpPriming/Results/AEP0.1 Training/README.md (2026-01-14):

# Joint in-person training

## Logistics

Initial in-person training was provided by AMYBO's Dr Martin Currie for both Imperial College and Edinburgh students at Edinburgh University's Chris French Laboratory from 18-21 November 2025.
<!-- TODO: let me know if you'd like your names mentioned here and I'll add them, we could also link to our LinkedIn profiles or link-in-bios if you like | assignee: @Bingqiao @Amir @Teo -->
<!-- I think it would be nice to have our names but I personally don't feel the need to link any bio of mine. Teo -->

## Assembly and Calibration

### Procedure

The main focus of the training was assembly and calibration of three AEP0.1 prototypes following the [AEP0.1_Assembly.md](AsepticElectroPioreactor/CARMA_PumpPriming/Assembly/AEP0.1_Assembly.md) guide.  One prototype was assembled by each of the three students.

Views of partial assembly (without pumps or media bottles set up)
Side on view:

Top down view:


### Assembly issues

Improvements to the assembly procedures were made during the course of the training.  See [Other Issues](#other-issues) below for the most significant examples.

### Software issues

Following the documented software installation, we were unable to SSH into the AEPs.  This issue took a long time to diagnose and required consultation with Labcrafter and Pioreactor.  We initially conflated the issue with a trivial LED not lighting issue which was resolved by Pioreactor in that day's nightly Pioreactor software build. Cameron Davidson-Pilon of Pioreactor found that it was due to an [issue with the Raspberry Pi Imager](https://github.com/raspberrypi/rpi-imager/issues/1170) which was resolved by using an earlier version of the Imager.
<!-- TODO: Insert calibration results | assignee: @Bingqiao @Amir @Teo -->

## Media

Media was made up as per [MediaFormulation.md 2025-11-12](https://github.com/amy-bo/electroPioreactor/blob/ba442ae67962f1ee57649e94e9f0302e0077b55f/Media/MediaFormulation.md)<!-- TODO: insert variations from MediaFormulation.md 2025-11-12 | assignee: @Bingqiao or anyone who noted details -->.

Versions were sterilised by autoclaving and by filter sterilisation.
<!-- TODO: define filter type - was it 0.2 μm? what material? | assignee: @Bingqiao or anyone who noted details -->
<!-- TODO: detail the media discolouration and precipitation issues | assignee: @Bingqiao or anyone who noted details -->

## Heterotrophic culture

A heterotrophic culture of Cupriavidus metallidurans was established using the above Media plus gluconic acid (sodium salt) as the carbon and energy source.

<!-- TODO: insert results | assignee: @Bingqiao or anyone who noted them -->
<!-- TODO: Insert section on Autotrophic results and our planned next steps | assignee: @Bingqiao @Amir @Teo -->

## Autotrophic culture

Following sucessful heterotrophic culture of Cupriavidus metallidurans, autotrophic culture was attempted. Four reactors were seeded, two with an initial concentration of 0.001 OD600 (the same as the sucessful heterotrophic culture) and two with an initial concentration of 0.02 OD600 (an arbitrary high concentration to try and guarantee growth). Both were grown as batch culture with the carbon free MM of 20mL for ~17 hours at 30C with stirring. No growth was observed. Plausible causes of no growth:
- Suboptimal media composition
- High voltage
- Inconsistent temperature maintenance
- Ineffective CO₂ sparging and thus O₂ dispelling
- Issues with anode discoloration (may be related to media composition)

Planned next steps are to:
- introduce intermittent CO₂ sparging
- Experiment with a current limiter
- Remove variables to determine autotrophic growth limiting steps
- Experiment with media composition such as changing concentration of or removing iron or phosphate

## Sparging

The system was set up for continuous sparging of CO₂, however this presented three issues:

### 1. Water in CO₂ lines

The bubble counters, when set up as per manufacturers instructions, resulted in rising bubbles passing water into the downstream CO₂ lines.  This was unacceptable as over time it would impact the hydrophobic gas filters.

Various configurations were discussed and a number of them tested.  Replacing the distilled water with mineral oil improved the situation, but still required a restrictively low gas flow to ensure no mineral oil entered the downstream CO₂ lines.

### 2. Oxygen Purging Sensitivity

The low flow rates of CO₂ made the positioning of the CO₂ sparging tube extremely critical in terms of O₂ bubble dislodgement from the anode.  An adaptation was made using o-rings to maintain the tube's location, however this may have adversely impacted fluid flow.

### 3. Optical Density Measurement Issues

While intermittent sparging previously triggered a postponement of optical density measurement, continuous sparging could not.  This meant that the bubbles could interfere with optical density measurement, which was then also highly sensitive to optical density measurement.

### Sparging Solution

It was decided that intermittent sparging should resume, this meant that the bubble counters were no longer required, that CO₂ bubbles take a much broader range of pathways, so the sparging tube's location was less critical.  This required a significant design change in order to avoid [CO backflow](PastResearch/Brown-HarrisLab/1.CO2backflowDiagnosis-EliSilver.md).

## Anode Discolouration

At the end of the experiments the platinum plated titanium anodes were noted to have discoloured to brown in the areas closest to the cathode, with rainbow discolouration further away:
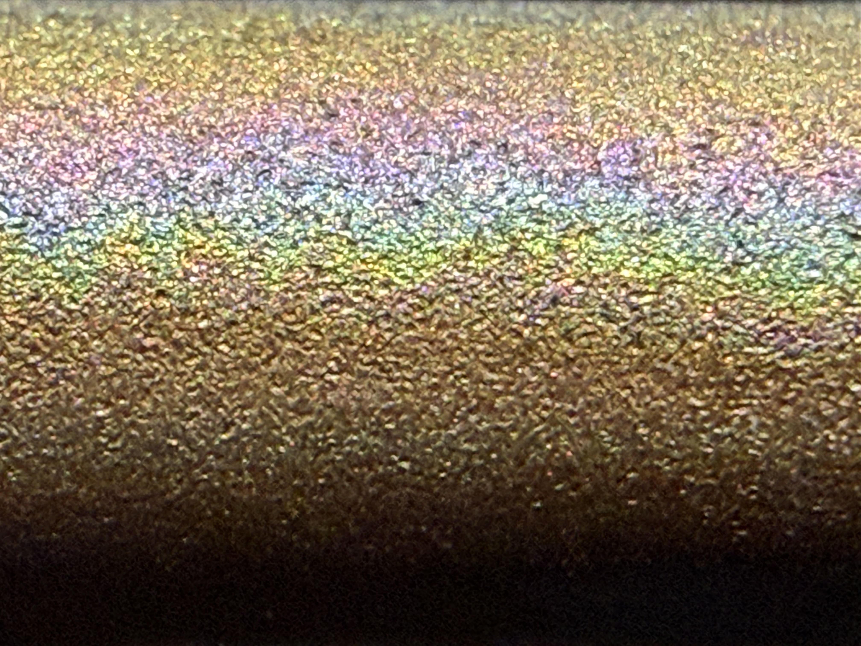
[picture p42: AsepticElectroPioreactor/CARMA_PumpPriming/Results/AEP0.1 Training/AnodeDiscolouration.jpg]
Platinum plated titanium anode discolouration - At the bottom, above the shadow, we see the brown discolouration that we found on the cathode-facing side of the anode. Above this you see a transition to rainbow discolouration. At the very top you can see the natural platinum colour.


## Other Issues

### Crocodile Clip Detachment

The new higher quality crocodile clips purchased for the cylindrical electrodes easily detached.  This inspired [Top Stop improvements](https://github.com/amy-bo/electroPioreactor/commit/e0ebc9f5677bb1e9d91fb322b1b6322d0b47057f) that remove the need for crocodile clips and reduce the risk of electrode polarity inversion.

### Suboptimal Raft Order

Traditionally AMYBO located the SodaStream cyclinder in the centre of the raft for stability.  However this makes the media bottles harder to observe in large rafts and results in excessive peristaltic pump tubing run lengths.  The raft was reoriented to place sodastream cylinders at back - this improved visibility and reduced peristaltic tubing run lengths.

### Vial Fragility

One of the [vials](https://labcrafter.co.uk/products/20ml-glass-vial-cap-s-with-ports-and-stir-bar) dropped and smashed. It would be prudent to carry boxed spares of critical components.

### Vial Cap O-Ring Dislodgement

The vial cap o-rings tended to fall out, making aseptic technique difficult.  This inspired a vial cap [design improvement](https://github.com/amy-bo/electroPioreactor/commit/88e3c8db04196599436d371a5588a67b8afb526a) with a lip to retain the o-ring.

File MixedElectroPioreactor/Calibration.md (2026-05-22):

# MEP Calibration (Edinburgh MSc)

Six things to set up per unit before any experiment: stirring (PWM↔RPM), peristaltic pumps, OD600 (cell-density curve vs photodiode signal), vial level, CO₂ flow rate, and electrolysis (Voltage across electrodes and Pioreactor Controlled Current through electrodes at 2.5 % LED D). Run on ed04 and ed05 in turn.

Pre-requisite: both units assembled per [Assembly](Assembly-EdMSc26.md), and reachable on the network.

## 0. Self test

Follow [Pioreactor’s self test guide](https://docs.pioreactor.com/user-guide/pre-flight-hardware-check#step-1-run-a-self-test) to ensure everything is working as anticipated.

## 1. Stirring

Follow [Pioreactor’s really simple stirring calibration procedure](https://docs.pioreactor.com/user-guide/hardware-calibrations#stirring-calibrations).

## 2. Peristaltic pumps

Follow [Pioreactor's pump calibration guide](https://docs.pioreactor.com/user-guide/hardware-calibrations#pump-calibration) on the Protocols page. For each pump (media on PWM 3, waste on PWM 2):

1. When prompted, enter the target volumes to calibrate around (comma-separated, in mL).
2. For each prompted dispense: catch the output in a tared weighing boat on the analytical balance, then enter the measured volume back into the UI (1 mL water ≈ 1 g at room temp).
3. Repeat across the prompted set.
4. Save the calibration. The UI will refuse to dose until both pumps are calibrated.

Record on the unit's calibration sheet: date, balance ID, who ran the calibration, ml/s at 100 % duty for each pump.

## 3. OD calibration

Follow [Pioreactor's "Standard curves for OD600 readings"](https://docs.pioreactor.com/user-guide/calibrate-od600). This sets the relationship between raw photodiode signal and cell density for *this unit*, so OD traces from ed04 and ed05 can be compared meaningfully. It lives on the **Protocols** page (Device = `od90` for the standard 90° channel).

You'll need a series of vials with **known OD600 values** (measured against a benchtop spectrophotometer) plus a media-only blank. The UI walks you through naming the calibration, recording each standard, and fits a curve from the live chart. See [§ Running the calibration](https://docs.pioreactor.com/user-guide/calibrate-od600#running-the-calibration) for the step-by-step.

**Per unit; redo every 6 months or whenever the optical setup changes.** The per-experiment **OD blank** done at experiment start (see [Operation § Batch step 4](Operation.md#1-batch-experiment)) is a separate, additional baseline correction.

Record on the calibration sheet: date, who ran it, spec model used for reference, OD600 of each standard.

## 4. Level

1. Dry and weigh your vial
2. Add water to your media vessel
3. Add water to your vial to the level that you want to operate at (say 14ml)
4. Weigh your vial to confirm the volume of water in it
5. Adjust your product/waste line so that it is only just submerged at the desired water level
6. Run the media and product/waste pumps
7. Go to step 4 and repeat until you have the desired volume of water after running the pumps

## 5. CO₂ flow rate

The FZone regulator has a fixed, non-adjustable outlet pressure. The only variable you control on the gas side is the needle-valve opening.

1. Confirm the SodaStream is open (the valve directly on top of it is fully down)
2. Run a 1/16" tubing line from one of the vial's exhaust luer locks to a measuring cylinder inverted in a water bath. Plug the other exhaust luer with a luer plug or tie a knot in its line.
3. Sparge CO2 into the water bath until it is saturated with CO2 (you could monitor for no further pH drop to determine saturation.)
4. From the web UI's relay activity tab, open the solenoid (relay on) for a fixed time.
5. Record the volume of CO₂ collected.
6. Compute flow rate (ml CO₂ per second of solenoid-open).
7. Adjust the needle valve and repeat until you hit your target.
8. Record needle-valve setting (turns from fully closed) on the unit's calibration sheet.

If you cannot get to the target flow within sensible needle-valve travel, the problem is one of: (a) needle-valve creep, (b) a kinked line, (c) a leak at one of the Loctite-577 joints. If you suspect (c) try pipetting washing-up liquid in water at the joints and watching for bubbles.

## 6. Electrolysis (V and I at 2.5 % LED D)

1. With the bicarbonate-filled vial seated in the Pioreactor, set LED channel D to **2.5 %** in the web UI.
2. Within 30 s you should see bubbles on both electrodes. The cathode (stainless steel, black lead) should bubble at roughly twice the rate of the anode (Pt-plated Ti, red lead). This is the H₂:O₂ molar 2:1 ratio you would expect.
3. Measure voltage across the electrodes with a multimeter on the DC volts range, probes on the two ring-crimp terminals. Record V on the calibration sheet.
4. Measure current through the electrodes by breaking one electrode lead, putting the multimeter inline on the DC current range (mA), and reconnecting. Record I on the calibration sheet.
5. Set LED D back to 0 % at the end of the check.

Once steps 1–6 are signed off for both ed04 and ed05, the units are ready to run [Operation.md](Operation.md) for real.  However it is recommended that you return and validate that values haven’t changed before and after each experiment.  If you notice significant change you will need to recalibrate.

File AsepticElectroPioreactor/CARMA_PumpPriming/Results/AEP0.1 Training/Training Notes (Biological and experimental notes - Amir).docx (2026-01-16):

Training Notes

Primarily biological information and testing results

18/11/2025:

- Assembled the main Pioreactor vessel
- Prepared the electrolytically competent media for Cupriavidus metallidurans cultivation based on the Sydow optimised media by Martin (removal of all phosphates)
  - 25ml of meso-nutrients; 1.25ul of trace elements, 85ul of iron sulphate
    - For heterotrophic variant add 10mM (final concentration) of gluconic acid
  - https://github.com/amy-bo/electroPioreactor/tree/main/Media
  - The media was filter sterilised using a 0.2 micron filter due to sedimentation and colour change of trace elements after autoclaving
    - At that moment, we did not have Manganese sulphate Monohydrate, instead we used 0.317 g of Manganese II Sulphate Tetrahydrate (molar quantity ends up the same)
  - Inoculated 2x 25ml of media at 30C for 17 hours, heterotrophically
    - Original liquid culture OD of 0.614
    - 1st culture final OD of 0.001
    - 2nd culture final OD of 0.02

19/11/2025:

- Finish the pioreactor set-up
- Overnight ODs
  - Starting point 0.001 = 0.160 OD
  - Starting point 0.02 = 1.015 OD
- Electrical analysis of the system

| Pioreactor 1 | Pioreactor 2 | Pioreactor 3 | Pioreactor 4
Voltage | 3.38 | 3.41 | 3.36 | 3.28
current | 0.012 | 0.012 | 0.012 | 0.012

- Inoculated the pioreactor with 15ml of autotrophic media (without gluconic acid) to final ODs of 0.001 (pioreactor 1 and 2) and 0.02(pioreactor 3 and 4)

20/11/2025:

- No growth due to faulty OD sensors. Possible causes are:
  - Suboptimal media composition
  - High voltage
  - Inconsistent temperature maintenance
  - OD sensor being blocked by an electrode
- Further pioreactor training continued, such as setting up media and waste tubes and how to calibrate it.

21/11/2025:

- Carried out a conductivity test of the autotrophic media
  - 6.48MS at 18.8C
  - 6.55 MS at 19.1C

Percent output (as shown on the software) | Voltage
1% | 2.510
2% | 2.619
3% | 2.720
4% | 2.8
5% | 2.913
6% | 2.961
7% | 2.97

- Noticed the discoloration on the cathode, near the CO2 sparging tube

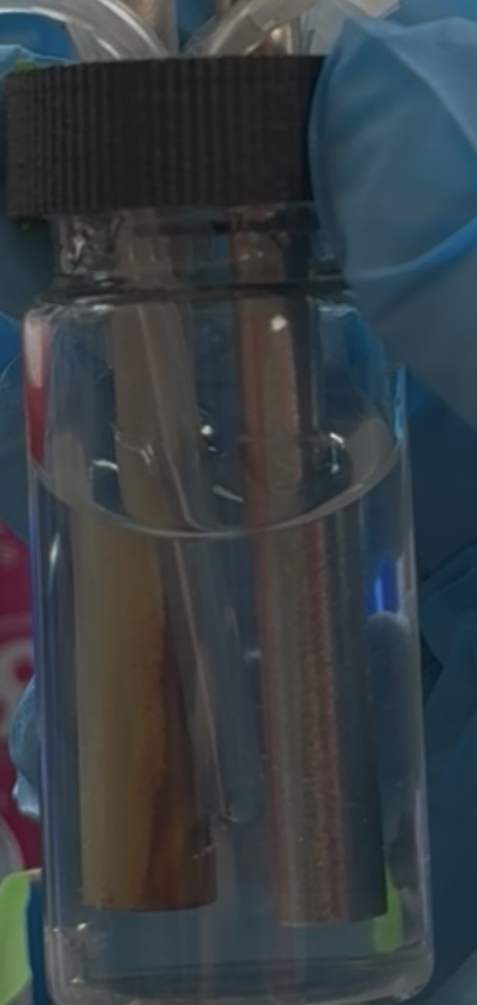
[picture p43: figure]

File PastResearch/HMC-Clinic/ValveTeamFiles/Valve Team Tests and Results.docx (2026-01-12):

Valve Team Tests and Results

The valve team found in the testing phase that 10N was not enough to fully close the tubing. The team was using the observed value found using the above suction procedure, which did not account for pressure buildup from the CO2 canister. As such, the team had to pivot to the mechanical advantage design as seen outlined in the spring semester section. Early tests of this prototype determined that, though the carbon filament could withstand the force, the tubing holder was flexing. Therefore, a temporary support structure was designed as shown in the figure below.

Using this design, as seen in Figure 19, the valve could fully pinch the 20cm 1/16" ID Silicone tubing and prevent all CO2 from continuing into the Pioreactor vial. The figure below verifies that, when the valve is powered off, there is no CO2 continuing into the valve and, when the solenoid is powered with 12V, the valve opens. The valve pulls a maximum of 2.36 Amps when powered by 11.31V which is within the constraints of the design.

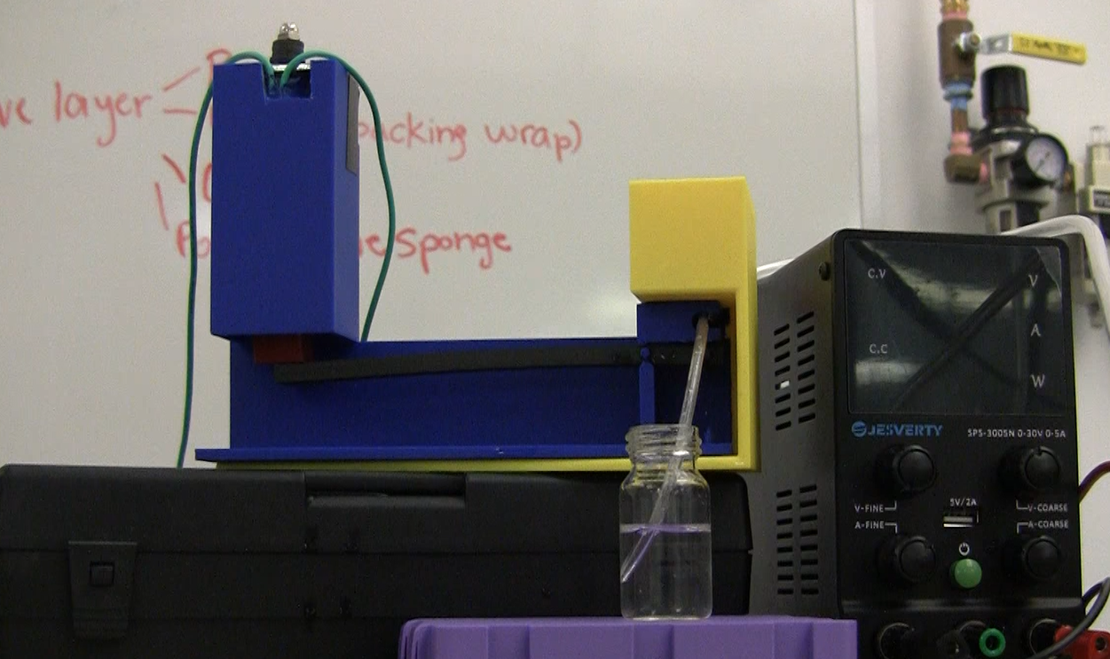
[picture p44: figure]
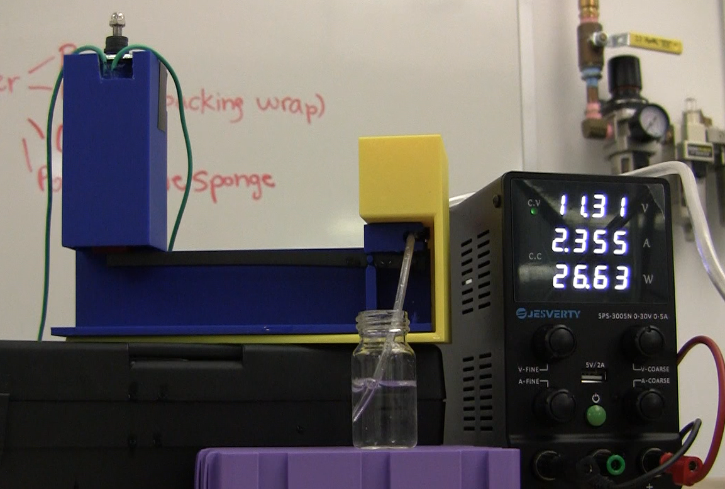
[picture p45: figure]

(Left) Solenoid pinch valve in the NC position (Right) Solenoid pinch valve powered and fully open

This visual inspection allowed the team to determine that the design met the deliverable.

Valve Team Future Recommendations

The solenoid valve is functional, but has some design flaws that can be addressed in future work. The first of which is the lever occasionally slipping out of alignment, preventing the solenoid hat from coming into contact with it and making the valve non-functional. This can be corrected either by adding vertical alignment supports, or by making the solenoid hat and lever one continuous piece. Additionally, the valve is large and, now that the proof of concept prototype has been verified, if the same ratio is kept it is possible to shorten the lever and therefore the entire footprint of the valve system. Material selection would have to be made with careful consideration as decreasing the size of the lever increases the stress in the material, making it more susceptible to fatigue stress. Finally, the design of the valve could be changed to allow for more seamless integration into the system. Currently, the pinching area is very large (0.5 in) and could be shrunk to better accommodate the short 20cm 1/16" ID Silicone tubing. Additionally, the supports can be integrated into the design and the tubing holder can be made thicker to stay rigid under the high applied force. A mock-up of this integrated support design can be seen in the figure below.

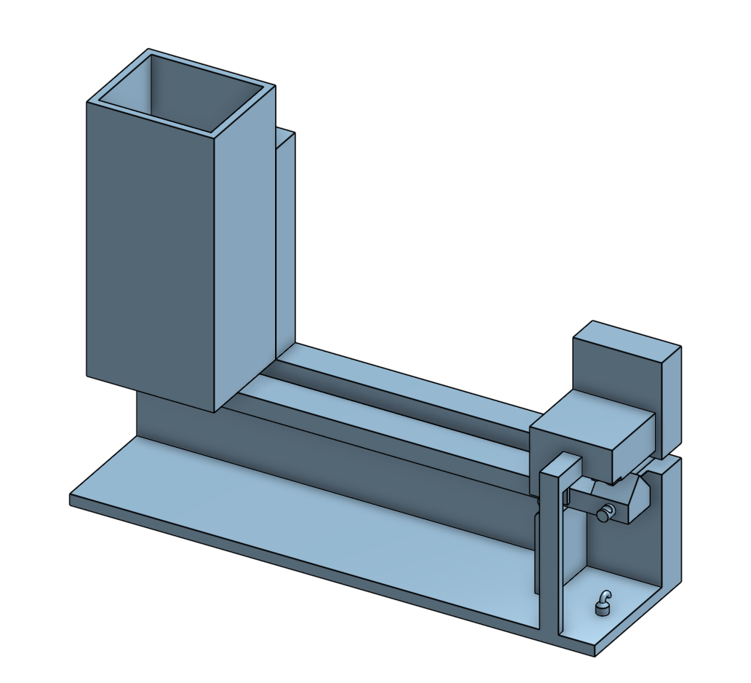
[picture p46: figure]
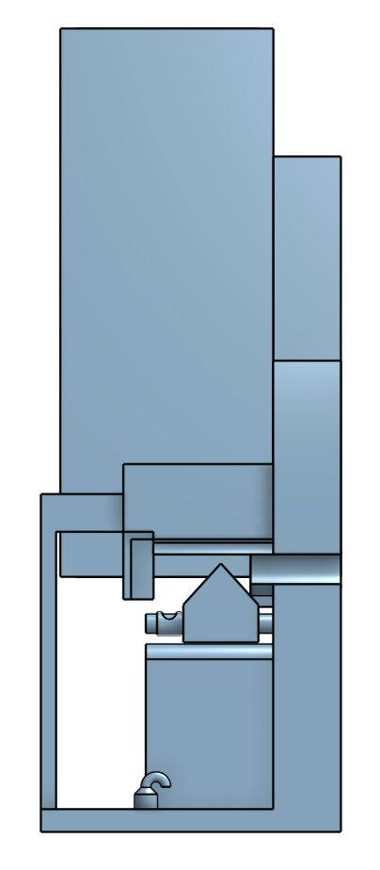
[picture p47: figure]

Figure 20: Solenoid Pinch Valve with Lever and Integrated Supports

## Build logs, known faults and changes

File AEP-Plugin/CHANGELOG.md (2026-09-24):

# electroPioreactor Plugin — Changelog

## Unreleased — card install route

No code change. Documents the card install route in `README.md`: flash a
stock Pioreactor image, drag the `pioreactor` folder from the card bundle
onto the `bootfs` drive, boot. Adds `scripts/make-card-bundle.sh` and a
`card-bundle` GitHub workflow that builds
`electroPioreactor-card-bundle.zip` (the plugin wheel under
`pioreactor/plugins/`) and attaches it to each GitHub release. Depends on
boot-partition plugin support in the Pioreactor image, proposed upstream
from <https://github.com/amy-bo/CustoPiZer/tree/bootfs-plugins> and accepted
in principle by Pioreactor on 2026-09-24. The SSH route remains documented
for older images.

## v0.6.7 (2026-05-10) — preserve key case in config.ini writes

Pre-v0.6.7 the plugin used a default `configparser.ConfigParser()` in
three runtime writers (`_save_all_config`, `_save_config`,
`_clear_unit_config`) and in the install-time
`scripts/patch-config-ini.py`. Default `ConfigParser` calls
`optionxform = str.lower` on every key as it parses, so a write-after-read
silently lower-cased every existing key in `~/.pioreactor/config.ini` —
including the `[leds]` LED-channel labels (A/B/C/D), and PID gains
(Kp/Ki/Kd) in `[stirring.pid]`,
`[dosing_automation.pid_morbidostat]`, and
`[temperature_automation.thermostat]`. Pioreactor itself uses
`ConfigParserMod` (`optionxform = str`) and looks all of those keys up
case-sensitively, so the corruption hard-failed every PID-controlled job
and broke the LED-label resolution OD reading depends on.

(Note on scope: `[od_config.photodiode_channel]` upstream uses **numeric**
keys 1/2/3/4, not letter keys, so it has no case-sensitivity bug. Letter-
key corruption appears in `[leds]`, not in the photodiode-channel section.
A first attempt at this fix on a feature branch wrongly targeted
photodiode_channel; the parallel `vibe pioreactor` session caught the
mismatch by inspecting an actual ed05 config.ini against the upstream
template before deploying.)

### Fix

All four ConfigParser sites now use `pioreactor.config.ConfigParserMod`
(case-preserving — the same class Pioreactor uses for its own config
machinery). The conftest stub now provides `ConfigParserMod` so off-device
tests still load the plugin.

The PWM-4 guard from v0.6.6 is preserved (test pinned).

### Tests

`tests/test_patch_config_ini.py` (new, 5 tests) pins case-preservation on
round-trip across `[leds]` letter keys, `[od_config.photodiode_channel]`
numeric keys, and the three upstream PID-gain sections, plus the PWM-4
guard. Existing 46 tests still pass — total 51 pass off-device.

### Note on already-corrupted units

A pre-v0.6.7 install of this script will have lower-cased keys in
`~/.pioreactor/config.ini` on whichever unit it ran on. v0.6.7 prevents
new occurrences but does not retroactively repair such files — only
Martin's own dev unit hit this in practice and it was hand-corrected
before release, so no repair pass is shipped.

## v0.6.6 (2026-05-08) — PR-16 review feedback (Gerrit)

Cleanup pass addressing the inline comments on PR #16. No behaviour change
for the running plugin; minimum supported Pioreactor version bumped to
**26.5.0**.

- **Drop the PR #615 tarball-patch flow.** Pioreactor 26.5.0 (released
  2026-05-07) ships PR #615 natively, so the transitional hot-patch is
  obsolete. Removed `scripts/apply-pr615-patch.sh`,
  `scripts/revert-pr615-patch.sh`, `transitional/pioreactor-static-pr615.tar.gz`,
  and the README "step 3" section. README "Pioreactor version compatibility"
  now states the 26.5.0 minimum and points users at `pio update`.
- **`patch-config-ini.py` no longer silently overwrites `[PWM] 4`.** If the
  channel is already mapped to a non-`relay` label, the script refuses with
  a non-zero exit and a clear remediation message instead of clobbering the
  user's wiring.
- **Repository hygiene.** `.claude/` and `.vibe/` added to `.gitignore`;
  `.claude/settings.local.json` and `.vibe/copy-latest.txt` removed from
  version control. `pi02-setup-notes.md` (development notes specific to one
  unit) removed from the repo.
- **`TODO.md` → `CHANGELOG.md`.** Naming reflects what the file actually
  is.

### Deferred to v0.7

Gerrit also flagged that the LED channel is hardcoded to `D` and the YAML
descriptions point specifically at PWM `4`. PWM is in fact already
configurable via Pioreactor's `[PWM] N = relay` label indirection (see
`pioreactor_electropioreactor_plugin/electropioreactor.py:89`). Making the
LED side equivalently configurable, and updating the YAML descriptions to
match, is the v0.7 work. Branch:
[`configurable-led-channel`](https://github.com/amy-bo/electroPioreactor/tree/configurable-led-channel)
(spec at `AEP-Plugin/v0.7-SPEC.md`).

## v0.6.5 (2026-05-04) — init ordering, no more masked ValueErrors

Moved timer/state attribute initialisation (`_sparge_timer`, `_stop_timer`,
`_od_resume_timer`, `_is_sparging`, `_od_paused`, `reset_to_defaults`) to
the top of `__init__`, before any validator that can raise. Without this,
a non-positive `sparge_duration_seconds` from the Advanced modal triggered
`_positive` to raise `ValueError`, BackgroundJob's exception cleanup then
called `_cancel_timers`, and the user saw

```
Failed to cancel timers during cleanup: 'ElectroPioreactor' object has no
attribute '_sparge_timer'
```

instead of the actual validation error. The cleanup path is now safe
regardless of which subsequent line in `__init__` fails.

## v0.6.4 (2026-05-04) — YAML schema + plugin install path

Two fixes that together let the UI actually render the plugin in
**Activities** on current Pioreactor:

- **YAML schema**. Pioreactor's `BackgroundJobDescriptor` /
  `PublishedSettingsDescriptor` use `forbid_unknown_fields=True` and only
  allow `key, type, display, description, default, unit, label, editable`.
  v0.6.2 added `min` / `max` / `step` to `published_settings` for UI input
  validation; current Pioreactor rejects the file silently
  (validation error logged via `report_error`, descriptor dropped). Stripped
  those fields. Range enforcement still happens at runtime in the job
  (`_clamp_power`, `_positive`).
- **Install target path**. Pioreactor's
  `web/utils.py:load_background_job_descriptors` scans
  `~/.pioreactor/ui/jobs/` (built-ins) and
  `~/.pioreactor/plugins/ui/jobs/` (plugin descriptors). The legacy
  `~/.pioreactor/ui/contrib/jobs/` is no longer scanned. README install
  step updated to deploy to the correct path.

## v0.6.3 (2026-05-04) — defer hardware import

`from pioreactor.hardware import PWM_TO_PIN` at module level fired
Pioreactor's `__getattr__` deprecation lazy-resolver, which calls
`get_pwm_to_pin_map()` and `Path(environ["DOT_PIOREACTOR"])` on access.
That broke `pio plugins list` from interactive shells (Pioreactor sets
`DOT_PIOREACTOR` via systemd / `/etc/pioreactor.env`, not
`/etc/environment`). Moved the import inside
`ElectroPioreactor.__init__`. Module imports cleanly regardless of env
state; instantiation still requires `DOT_PIOREACTOR`, which is correct.

## v0.6.2 (2026-04-30) — polish pass

After the v0.6.1 root-cause fix, a Superpowers code review surfaced a list
of pre-existing rough edges. v0.6.2 addresses them in a single focused
release:

- **CI**: added `.github/workflows/aep-plugin-tests.yml` running `pytest tests/`
  on push and PR. Pre-v0.6.2 the suite had never been executed by a machine.
- **YAML input validation**: `sparge_duration_seconds` and
  `sparge_interval_minutes` now declare `min: 0.01` so the UI rejects values
  the runtime would silently swallow as `ValueError`. `step: 0.1` on the
  three `seconds` fields gives the spinner sensible increments.
- **Hardened shutdown**: `on_disconnected` and `on_ready_to_sleeping` now
  run each cleanup step (cancel timers, close solenoid, off LED, resume
  od_reading) under a `_safe()` wrapper so a failure in one step doesn't
  skip the others.
- **Init-time clamp logging**: when `__init__` clamps `electrolysis_power`
  to the `[0, 10]` range, it now logs the original-and-clamped values
  instead of silently overwriting the user's input.
- **Reset toggle self-clears**: `set_reset_to_defaults` now sets
  `self.reset_to_defaults = False` at the end so the YAML's "resets itself
  automatically after applying" claim matches in-memory state.
- **In-flight sparge invariant pinned**: a new test asserts that mid-sparge
  changes to `sparge_duration_seconds` apply to the next cycle, not the
  in-flight one (matching the YAML description). A future "fix" that
  silently changes this user-facing behaviour now fails CI.
- **Packaging**: `click` moved from `extras_require['dev']` (where it was
  miscategorised) to `install_requires`. `requirements-dev.txt` deleted —
  duplicated `extras_require['dev']`, single source of truth now.
  `__init__.py` exports `ElectroPioreactor` for clean downstream imports.
- **Docs**: README "41 tests" claim removed (was stale); install
  instructions use `pip install -e ".[dev]"` instead of pointing at the
  removed `requirements-dev.txt`.
- **Persistence smoke test**: new `TestPersistence` class exercises the
  real configparser + atomic-write path so a regression that breaks
  setter-to-disk persistence is caught off-device.

46 tests pass off-device (verified on Pi venv).

---

## v0.6.1 (2026-04-29) — data-layer persistence fixed

### What was actually wrong

`published_settings` declared each setting with only `{datatype, settable}`.
Pioreactor's `BackgroundJob._clear_caches` runs during clean-up and, for every
entry without `persist: True`, publishes a `None` payload to the retained MQTT
topic and zeros the corresponding row in the SQLite metadata DB
(`pio_job_published_settings`). Result: every Stop wiped our four settings from
both data sources. The Advanced modal subscribes to those retained MQTT topics;
with our values nulled, React was left holding whatever it last displayed.

The 0.5.2/0.5.3 atomic-write fixes attacked the wrong layer (config files were
fine), so they had no effect on the symptom.

### Fix

Added `"persist": True` to all four entries in `published_settings`. Same
pattern Pioreactor's own `dosing_automation` uses for `alt_media_throughput` and
`media_throughput`. Verified end-to-end on-device: after a CLI run with
electrolysis_power=7.5, sparge_duration=13, sparge_interval=60,
od_pause_after=4.2 and SIGTERM, both MQTT retained and `pio_job_published_settings`
still hold all four values. Pre-fix, only `$state` survived (4 prior runs of
electropioreactor showed only `$state` in SQLite).

### Also fixed in v0.6.1

`_pause_od_reading` and `_resume_od_reading` called `JobState.SLEEPING.to_bytes()`,
which doesn't exist on str-subclass enums. Threw on every sparge cycle (caught
silently by try/except, but spammed the log). Switched to `.encode()`. Off-device
tests previously passed because `conftest.py` stubbed `JobState` with its own
`.to_bytes()`; that stub was wrong and is now a `str` subclass to mirror upstream.

## Pioreactor version compatibility

The Pioreactor frontend (React) bug that caused the Advanced modal to require
a hard-refresh after Stop was fixed upstream in
[Pioreactor/pioreactor#615](https://github.com/Pioreactor/pioreactor/pull/615),
merged 2026-04-30. The fix lands in **Pioreactor 26.4.5+**; the latest tagged
release at the time of writing was 26.4.4 (2026-04-23).

**Users on 26.4.5 or later** see the modal display fresh values on every
re-open with no extra action.

**Users on 26.4.4 or earlier**: the README install flow (step 3) hot-patches
`pioreactor.web.static` with a pre-built bundle from
`AEP-Plugin/transitional/pioreactor-static-pr615.tar.gz` so the modal also
re-fetches on open. The hot-patch is reversible (the original bundle is
preserved at `pioreactor.web.static.pre-pr615.bak`). After upgrading to
26.4.5+, revert the hot-patch and the upstream-included PR #615 takes over.
The plugin's data layer (config files, MQTT retained, SQLite metadata DB)
is correct on both versions; the symptom was purely React component state.

## Reset toggle

`set_reset_to_defaults(True)` clears `[electropioreactor.config]` from both unit
config files (so `config.ini` defaults apply) then re-saves those defaults. The
toggle is intentionally *not* in `published_settings` — having it there caused
Pioreactor to replay the last `True` value on every restart.

## Atomic writes

`_save_all_config`, `_save_config`, and `_clear_unit_config` write via a
tempfile + `fsync` + `os.replace` to survive power loss mid-write.

## Relevant files

```
AEP-Plugin/pioreactor_electropioreactor_plugin/electropioreactor.py   — main plugin
AEP-Plugin/pioreactor_electropioreactor_plugin/ui/contrib/jobs/electropioreactor.yaml
AEP-Plugin/pioreactor_electropioreactor_plugin/additional_config.ini
AEP-Plugin/setup.py
AEP-Plugin/tests/
```

On device (`pio01`):

```
/home/pioreactor/.pioreactor/config.ini                        — global baseline
/home/pioreactor/.pioreactor/config_<unit>.ini                  — plugin-written, read by web API
/home/pioreactor/.pioreactor/unit_config.ini                   — plugin-written, read by job process
/home/pioreactor/.pioreactor/plugins/ui/jobs/20_electropioreactor.yaml   — UI descriptor (current path; was ui/contrib/jobs/ pre-v0.6.4)
/opt/pioreactor/venv/lib/python3.13/site-packages/pioreactor_electropioreactor_plugin/
/opt/pioreactor/venv/lib/python3.13/site-packages/pioreactor/web/static/                — Pioreactor frontend; on 26.4.4 or earlier the README install step 3 hot-patches this with PR #615
```

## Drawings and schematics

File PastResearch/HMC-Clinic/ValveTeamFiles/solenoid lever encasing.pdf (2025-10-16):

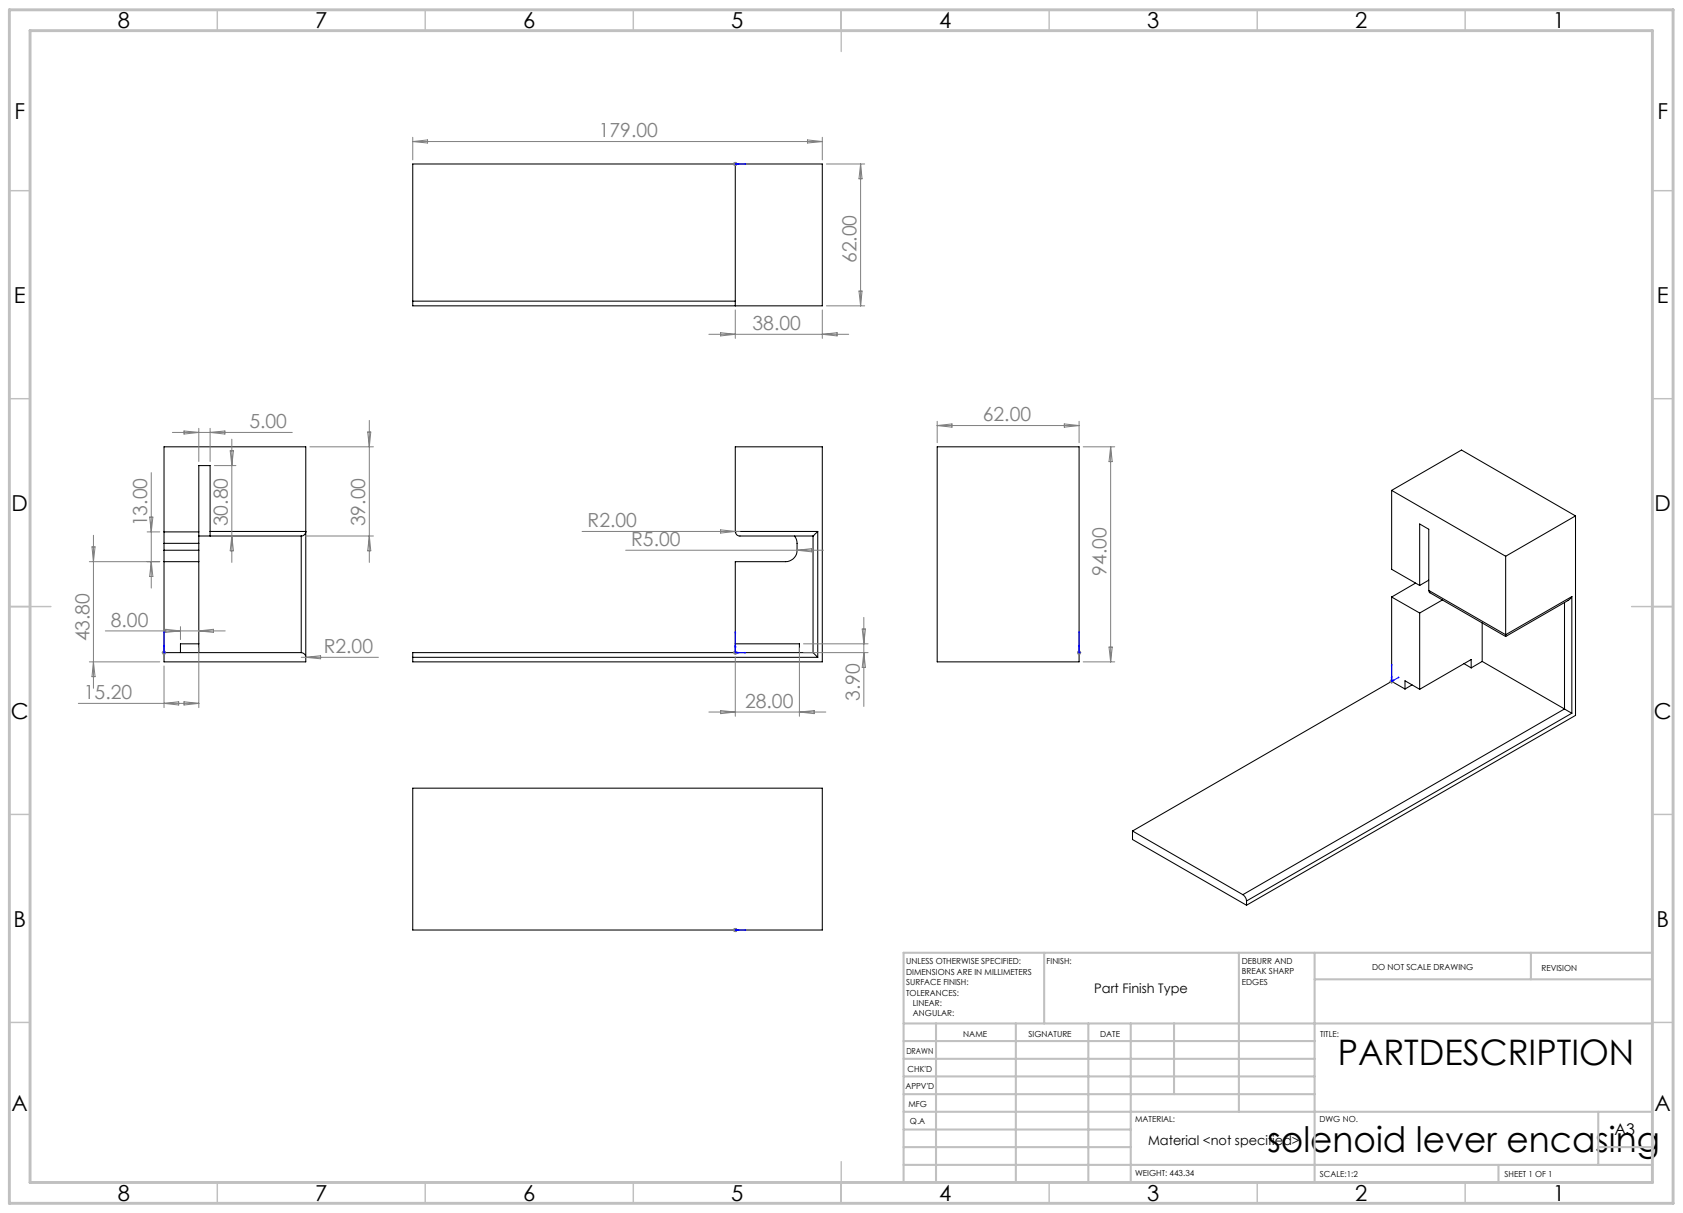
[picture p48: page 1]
FINISH:; DEBURR AND; BREAK SHARP; DO NOT SCALE DRAWING; REVISION; SCALE:1:2; SHEET 1 OF 1; WEIGHT: 443.34

UNLESS OTHERWISE SPECIFIED:
DIMENSIONS ARE IN MILLIMETERS
SURFACE FINISH:
TOLERANCES:
LINEAR:
ANGULAR:

Part Finish Type

NAME | SIGNATURE | DATE | | | | TITLE: PARTDESCRIPTION

DRAWN
CHK'D
APPV'D
MFG
Q.A | | | | MATERIAL: solenoid lever encasing | DWG NO. | A3 Material <not specified>

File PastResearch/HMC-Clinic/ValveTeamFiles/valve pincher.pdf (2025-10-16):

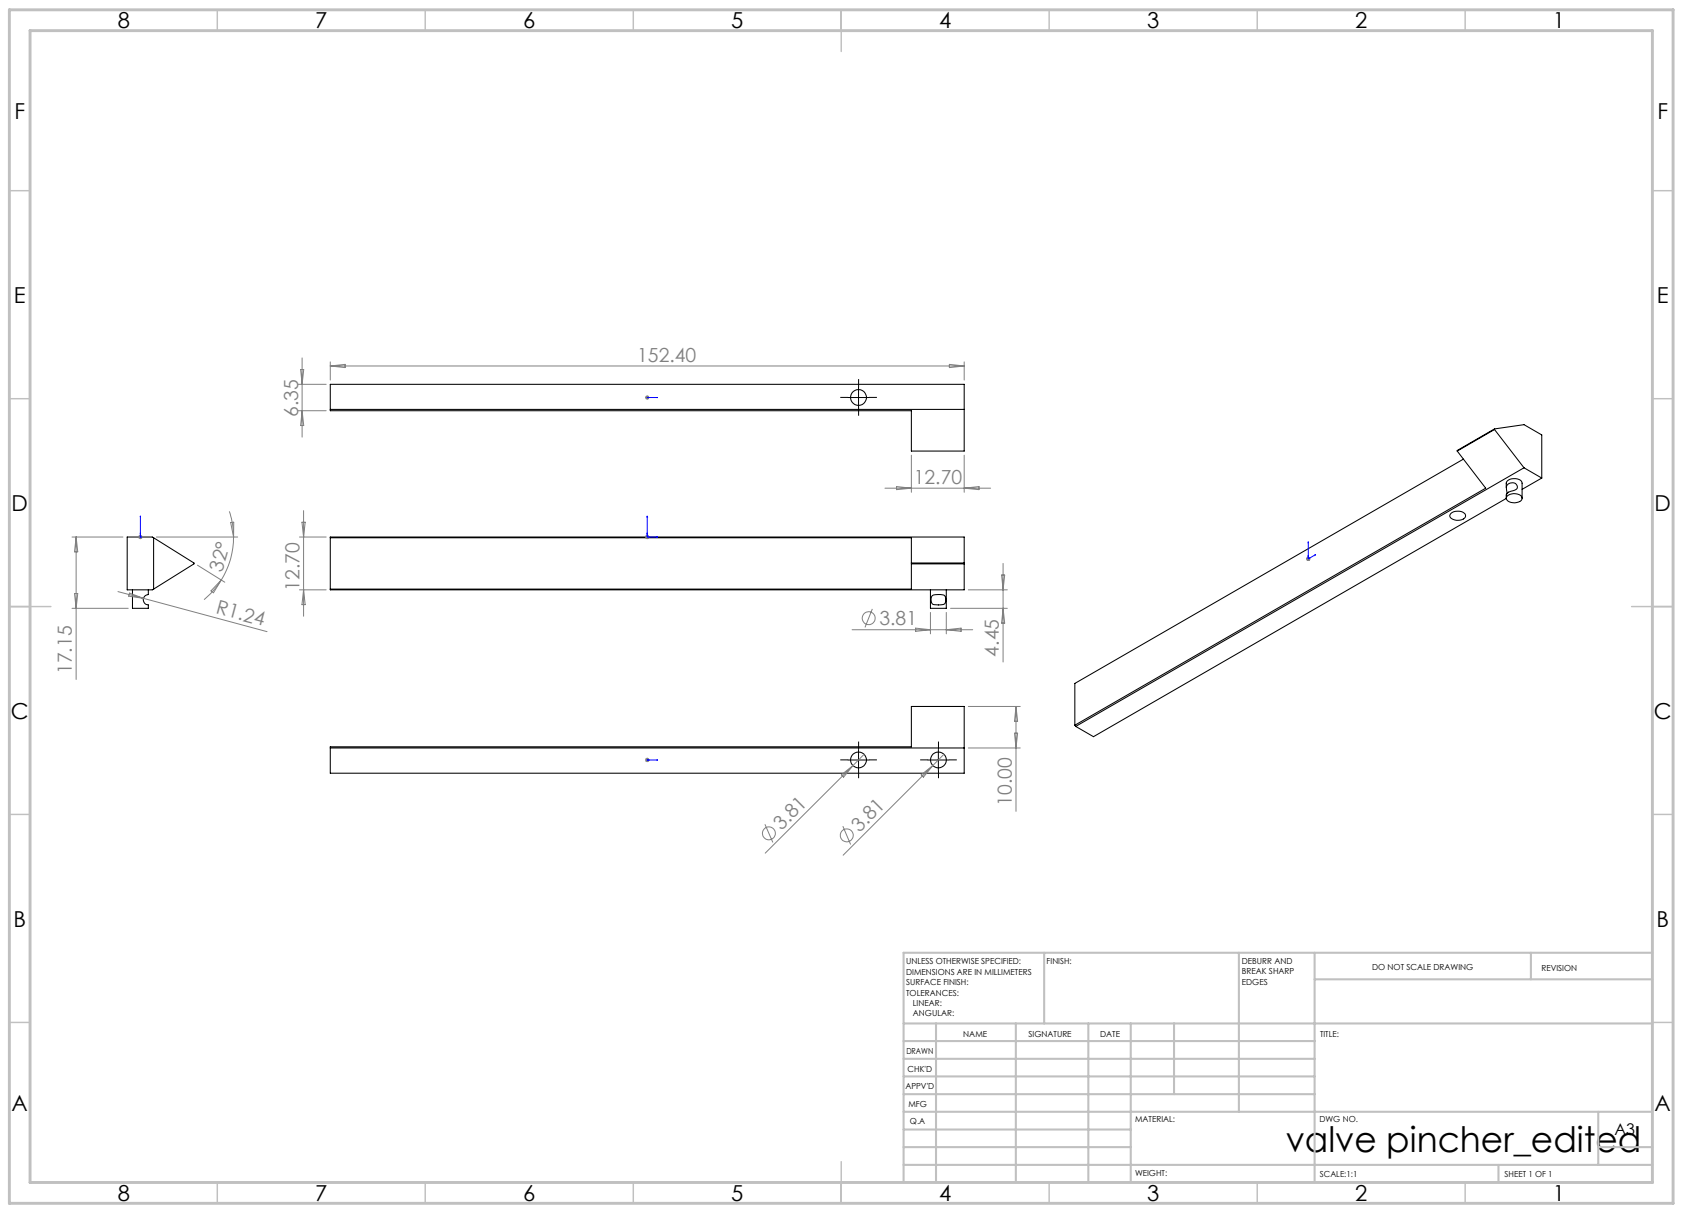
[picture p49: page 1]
FINISH:; DEBURR AND; BREAK SHARP; DO NOT SCALE DRAWING; REVISION; SCALE:1:1; SHEET 1 OF 1

UNLESS OTHERWISE SPECIFIED:
DIMENSIONS ARE IN MILLIMETERS
SURFACE FINISH:
TOLERANCES:
LINEAR:
ANGULAR:

NAME | SIGNATURE | DATE | | | | TITLE:

DRAWN
CHK'D
APPV'D
MFG
Q.A | | | | MATERIAL: valve pincher_edited | DWG NO. | A3

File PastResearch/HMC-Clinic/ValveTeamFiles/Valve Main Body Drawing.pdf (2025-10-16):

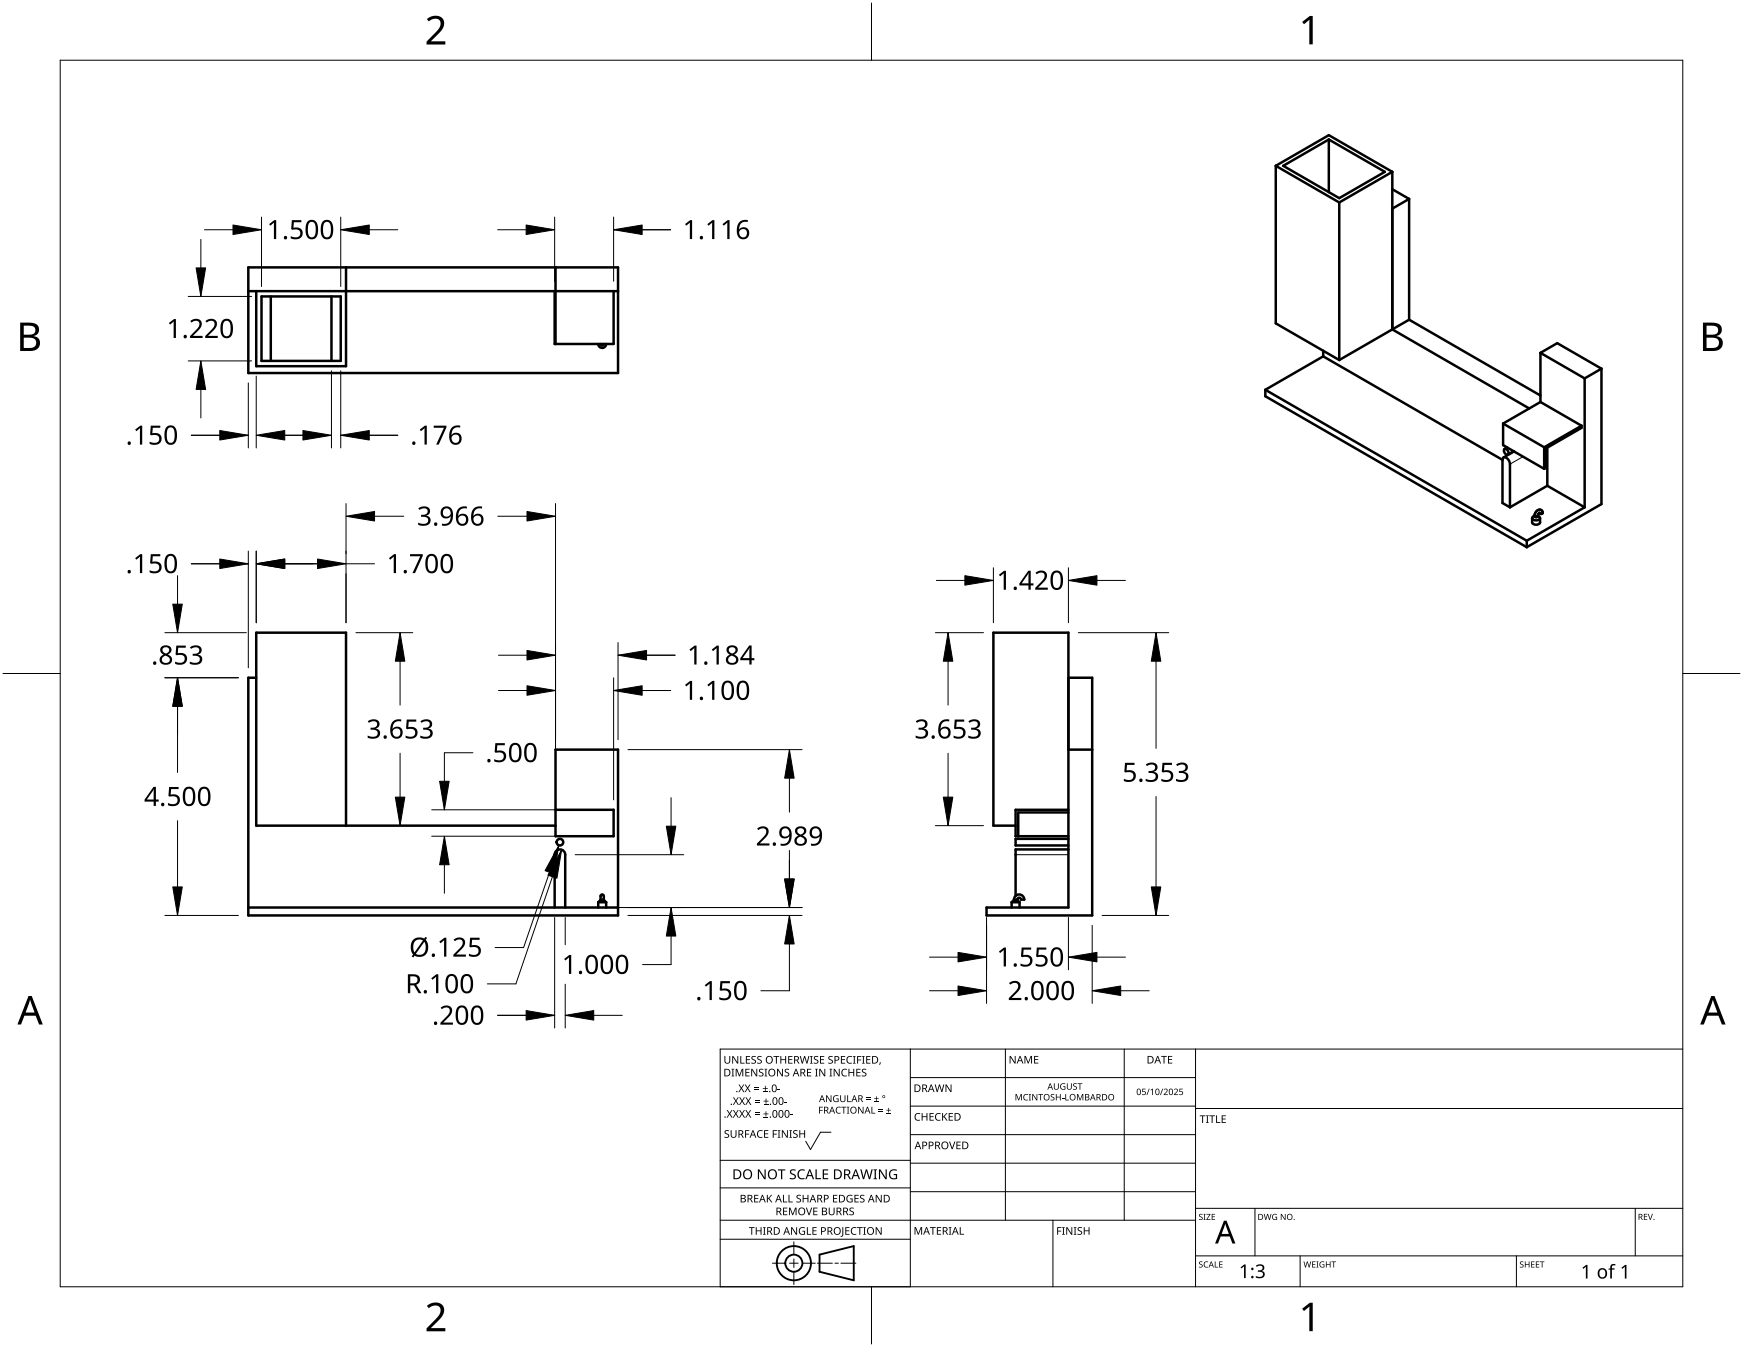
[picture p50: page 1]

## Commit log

2025-10-14 various rubbish from ChatGPT
    [gl18.scad, gl18.stl, trial thread.stl]
2025-10-14 first ChatGPT attempt
    [trial thread ring.scad]
2025-10-14 Fix syntax error by replacing broken thread generation with simplified helix-based internal thread module for valid rendering and accurate test ring geometry.
    [trial thread ring.scad]
2025-10-14 Replace placeholder internal thread with Dan Kirshner’s full metric_thread implementation for accurate, visible threading in the test ring.
    [trial thread ring.scad]
2025-10-14 reset to blank - starting afresh with new ChatGPT instance
    [trial thread ring.scad]
2025-10-14 Add parametric cylinder for vial cap test (8mm height, 27mm diameter)
    [trial thread ring.scad]
2025-10-14 Add Dan Kirshner internal thread modules + wrapper vial_cap_internal_thread(); keep separate from cap body
    [trial thread ring.scad]
2025-10-14 Implement GPI 24-400 internal thread test ring and render by default
    [trial thread ring.scad]
2025-10-14 bore too large removed thread stock; make bore < E so threads appear
    [trial thread ring.scad]
2025-10-14 Remove duplicate/simplified thread library that masked helical cut; keep verbatim Kirshner code only
    [trial thread ring.scad]
2025-10-14 Bypass broken polyhedron thread code; use robust linear_extrude twist cutter for visible internal threads
    [trial thread ring.scad]
2025-10-14 Fix undefined pitch warnings; increase resolution and generate visible helix
    [trial thread ring.scad]
2025-10-14 Swap to segmented helical cutter so threads are guaranteed visible in preview
    [trial thread ring.scad]
2025-10-14 Make the internal thread actually bite: deeper radial cut and 3 mm tangential cutter width
    [trial thread ring.scad]
2025-10-14 Add V-profile helical cutter with controllable flank angle; use shallow 40° included (half-angle 20°)
    [trial thread ring.scad]
2025-10-14 Correct internal-thread geometry: set cutter depth from target minor diameter (E) and stop bore from wiping the helix
    [trial thread ring.scad]
2025-10-14 Revert to HangerPeg02-49x4mm.scad
    [trial thread ring.scad]
2025-10-14 Remove hanger peg elements
    [trial thread ring.scad]
2025-10-14 invert cap (print top up)
    [trial thread ring.scad]
2025-10-14 apply GPI 24-400 parameters
    [trial thread ring.scad]
2025-10-14 turn into ring for test print
    [trial thread ring.scad]
2025-10-14 saved from Pioreactor Printables
    [Pioreactor_Zero_holder.3mf, trial thread ring.stl]
2025-10-14 Switch to BOSL2: clean 24-400 internal ISO thread (60°, 8 TPI) with print clearance; subtract through 27×8 mm ring
    [trial thread ring.scad]
2025-10-14 Use include for BOSL2 std to define global state vars; fix $tags_shown/$attach_to assertions
    [trial thread ring.scad]
2025-10-14 Add minor-diameter bore so internal thread subtraction is visible; keeps ISO V (60°, 8 TPI) geometry
    [trial thread ring.scad]
2025-10-14 Attempt to Fix thread engagement: leave 0.6 mm diametral stock below minor diameter so helix cuts full internal thread (ISO V, 8 TPI) instead of shallow groove.
    [trial thread ring.scad]
2025-10-14 fix geometry
    [trial thread ring.scad]
2025-10-14 contrain thread within bore
    [trial thread ring.scad]
2025-10-14 make formatting maintainable
    [trial thread ring.scad]
2025-10-14 tidy comments
    [trial thread ring.scad]
2025-10-14 reduce to 8mm ring for test prints
    [trial thread ring.scad]
2025-10-14 put cap in union, to remove ports
    [trial thread ring.scad]
2025-10-14 add ribs
    [trial thread ring.scad]
2025-10-15 add o-rings and electrodes
    [trial thread ring.scad]
2025-10-15 add up to 4 ports with electrodes or any number of ports without
    [trial thread ring.scad, trial thread ring.stl]
2025-10-15 set for Gerrit
    [trial thread ring.scad]
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2025-10-16 file away superseded designs
    [6mm_cap_v2.scad, 6mm_cap_v2.stl, blank_vial_cap.step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]
2025-10-16 make folder Vial Cap (singular)
    [6mm_cap_v2.scad, 6mm_cap_v2.stl, Vial Cap 2x6.1 + 5x3.2 v2.stl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]
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2025-10-21 add more suitable valve and correct with data from HPControl
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2025-10-23 correct valve descriptions
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2025-10-29 adjusted o-ring dimensions; electrodes should fit now
    [Vial Cap.scad]
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2025-11-10 works with PC-CF and 2mm CS electrode o-rings
    [Vial Cap.scad]
2025-11-11 add some tolerance for pt electrode; update readme
    [Vial Cap.scad]
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2025-11-17 Jonny of BKT confirmed "With those fittings you can’t go too tight (the washers are hard nylon) so don’t worry about over-tightening."
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2025-11-17 fix niggle post printing
    [ElectrodeTopStop.scad]
2025-11-17 edit to make seating guide
    [ElectrodeSeatingGuide.scad, ElectrodeSeatingGuide.stl]
2025-11-17 fix niggle
    [ElectrodeSeatingGuide.stl]
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2025-11-21 swap electrode colours
2025-11-28 add dovetail for vial cap o-ring
    [Vial Cap.scad]
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2025-12-03 make margin constant around slots
    [PinchSlider.scad]
2025-12-03 add triangular cutout to give easy in hard out from closed position
    [PinchSlider.scad]
2025-12-03 add printing tolerance on closed slot width
    [PinchSlider.scad]
2025-12-03 add missing ;
    [PinchSlider.scad]
2025-12-03 allow input diameters in mm or inches
    [PinchSlider.scad]
2025-12-03 add bung with retaining collar
    [PinchSlider.scad]
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2025-12-04 change to actual measurement of pinched tubing
    [PinchSlider.scad]
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2025-12-30 electrode wires can be attached to electrodes using M3 bolts
    [ElectrodeTopStop.scad, ElectrodeTopStop.stl]
2026-01-10 change tolerances for PC-CF
    [PinchSlider.scad, PinchSlider.stl]
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2026-01-12 remove spaces from paths
    [Bill of Materials for Solenoid Pinch Valve.xlsx, Valve Main Body.step, solenoid pinch valve encasing.SLDPRT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]
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2026-01-16 switch to bicarbonate, given potential issues with phosphate
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2026-02-09 Update README.md
    Added recommended and a few new required tools and to make sure to add power if using solenoid at appropriate step to avoid having to reassemble/recalibrate reactor after.
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2026-04-16 Refine protocol methodology: Sparging parameters, batch mode clarification, and sampling updates (#15)
    * add frozen sample for retrospective analysis
    * Add inoculation details and clarify batch mode
    * revise sparging volume and frequency
    * remove false assumption that we were in turbiostat mode in stage 3
    * clarify CO2 sparging
    * fix typos
    * duplicate and optimise equipment and materials checklists
2026-05-08 Add pioreactor-electropioreactor-plugin (#16)
    * add pioreactor-aep-plugin package scaffold
    Background job controlling CO₂ sparging and electrolysis (LED D) for the
    Aseptic ElectroPioreactor, with live-editable settings in the web UI.
    * refactor: rename plugin to pioreactor-electropioreactor-plugin
    - Rename package pioreactor_aep_plugin → pioreactor_electropioreactor_plugin
    - Rename job/class aep_sparging/AEPSparging → electropioreactor/ElectroPioreactor
    - Change sparge interval unit from hours to minutes (sparge_interval_minutes)
    - Fix published_settings: remove spurious "unit" key (not part of MQTT schema)
    - Fix on_ready_to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
2026-05-19 v0.6.7: preserve key case in config.ini writes (#19)
    * fix(aep-plugin): preserve key case in config.ini writes (v0.6.7)
    Pre-v0.6.7 the plugin used `configparser.ConfigParser()` (default
    optionxform = str.lower) at three runtime writers and the install-time
    patch-config-ini.py. A read-then-write through that parser silently
    lower-cased every existing key in `~/.pioreactor/config.ini`,
    including:
    [leds] A=IR / B / C / D
    [stirring.pid] Kp / Ki / Kd
    [dosing_automation.pid_morbidostat] Kp / Ki / Kd
    [temperature_automation.thermostat] Kp / Ki / Kd
    Pioreactor uses ConfigParserMod (optionxform = str) and looks all of
    those keys up case-sen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
2026-05-19 docs(carma): align [PWM] map with Pioreactor canonical (#17)
    The example [PWM] block had `2=media`, `3=waste` and a comment claiming
    hardware PWM lives on channels 2 & 4. Pioreactor's canonical config
    (verified against `config.dev.ini` on master, develop, and tag 26.4.4)
    is `2=waste`, `3=media` with hardware PWM on channels 1 & 3. Following
    the prior verbatim would have run media through the waste tubing and
    vice-versa.
    PWM 4=relay (CO₂ solenoid) is unchanged — it sacrifices `alt_media`,
    which the AEP doesn't use.
2026-05-21 docs: training pack for ed04/ed05 student deployment (Edinburgh MSc 2026)
    Five docs in MixedElectroPioreactor/ (README + Assembly, Calibration, Operation, Pre-Transport Check) plus a short AsepticElectroPioreactor/README so the MEP and AEP variants cross-link cleanly. Developed iteratively on the MScTraining branch; this is the final-state pack as it will ship with ed04 and ed05.
2026-05-21 docs: revert internal cross-repo links from absolute to relative (#22)
    Absolute https://github.com/amy-bo/electroPioreactor/tree/main/... URLs pull readers out of whatever branch they're on. Relative paths (../Components/..., ../AEP-Plugin, ../AsepticElectroPioreactor) travel cleanly across PR branches and forks.
    Reverts 5 links introduced in earlier MSc-training-pack work (Pass-4 cross-tree absolutisation + the AEP README + the MEP/AEP cross-link):
    - AsepticElectroPioreactor/README.md electroPioreactor plugin -> ../AEP-Plugin
    - MixedElectroPioreactor/README.md Aseptic electroPioreactor (AEP) -> ../AsepticElectroPioreactor
    - MixedElectroPioreactor/Assembly-EdMSc26.md TopStop -> ../Co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
2026-05-27 add GL45 holder for dovetail platform (#20)
    * add GL45 holder for dovetail platform
    * Update Components/GL45BottleHolder/GL45_holder.scad
    * address review feedback
    ---------
    Authored-by: Gerrit Niezen <me@gerritniezen.com>
    [GL45_holder.scad, GL45_holder_250ml.stl, duran_holder_platform_center_0.25L.stl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]
2026-05-29 Add 250/500/1000 ml size selector to the GL45 bottle holder (#23)
    * Add bottle-size selector to the GL45 holder (250/500/1000 ml)
    The GL45BottleHolder previously covered only the 250 ml Duran holder. This
    makes the SCAD parametric: set bottle_ml to 250, 500 or 1000 and it imports
    the matching upstream holder (already in source/) and fills that size's
    corner lettering.
    - corner lettering filled with rounded, full-height caps that sit flush with
    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
    [GL45_holder.scad, GL45_holder_1000ml.stl, GL45_holder_250ml.stl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]
2026-05-29 Revise CO2 transfer options and components in README (#24)
    * Revise CO2 transfer options and components in README
    Updated the README to reflect changes in recommended options for CO2 transfer, including a shift from continuous to intermittent sparging and added new components for the final solution.
    * Add link for 1/8" male blanking plug
    * Fix typo in 'Final Solution' heading
    * Add reducer links
    Updated the list of components for the final solution with links and additional details.
    * Fix links
    * Add filter details
    Updated the list of components for the CO2 transfer system, including new links and prices for the reducing hexagon nipple and hydrophobic filters.
    * Change section title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
2026-07-15 Parametric Vial Cap + electrode holder (septum seal, one-piece print) (#25)
    the top surface; cap positions are tuned per size and kept within the
    platform footprint so the dovetail teeth stay clear
    - GL45_holder_500ml.stl and GL45_holder_1000ml.stl added; the 250 ml STL is
    re-rendered from the same SCAD so al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
    [Vial Cap.scad, Vial Cap.stl]
2026-08-19 Vial Cap: latest vessel-cap revision + descriptive variable names (#28)
    Brings Vial Cap.scad to its current printed revision and adds the current
    STL (AEP2.0/Vessel Cap.stl), plus a full descriptive-naming pass that
    addresses the review comments on #25.
    - every parameter renamed to a self-describing name (<=3 words) so they
    read clearly in the customizer: port_d -> port_diameter,
    nut_af/nut_ac -> nut_across_flats/nut_across_corners,
    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
    [Vessel Cap.stl, Vial Cap.scad]
2026-09-24 Document the card install route and build the card bundle
    Users flash a stock Pioreactor image, drag the pioreactor folder from
    electroPioreactor-card-bundle.zip onto the bootfs drive, and boot. The
    README now leads with that route, forewarns that Imager ejects the card
    by default, and keeps the SSH route for older images. The example
    hostname is no longer ed04.
    scripts/make-card-bundle.sh builds the zip (the plugin wheel under
    pioreactor/plugins/ plus a README.txt) and the card-bundle workflow
    attaches it to each GitHub release, so the README's download link is
    stable across versions.
    Depends on boot-partition plugin support in the Pioreactor image,
    proposed from amy-bo/CustoPiZer branch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
2026-11-10 Media: review fixes (sources, electrode scale, acid stocks)
    From Gerrit's review of #37:
    - KIT's low iron figure is now attributed to Lisa as a personal
    communication (April 2026), paraphrased rather than quoted, with the
    KIT protocol and its 5.25 mg/L figure.
    - Dropped the claim that Bingqiao's replication of the low-iron medium
    gave no growth: no record of it could be found. His 2 April forum
    post kept the iron unchanged.
    - The scale warning no longer says carbonate on the anode as if
    settled: EDX cannot separate P from Pt, so calcium phosphate is not
    ruled out; the cathode is where pH rises and carbonate would be
    expected, and deposits were found there too; the 60 mM phospha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
